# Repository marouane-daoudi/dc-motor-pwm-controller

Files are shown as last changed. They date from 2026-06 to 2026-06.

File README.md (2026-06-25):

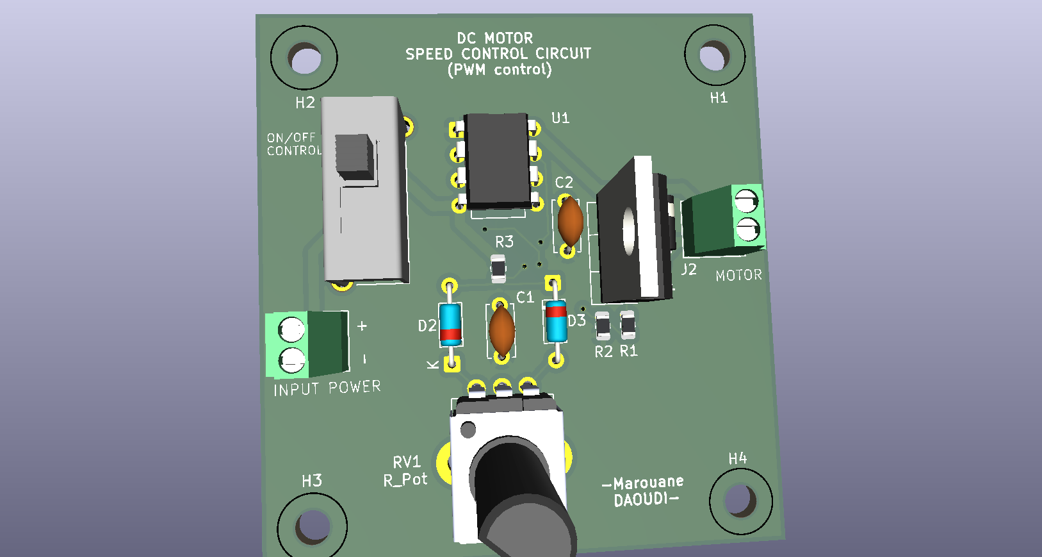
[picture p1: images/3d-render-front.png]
DC Motor PWM Speed Controller


# DC Motor PWM Speed Controller

A 2-layer PCB implementing a variable-speed DC motor controller 
using pulse-width modulation (PWM). The PWM signal is generated 
by a 555 timer in astable mode with an adjustable duty cycle 
controlled by a potentiometer. The design covers the full 
engineering workflow from circuit simulation in Proteus through 
PCB layout in KiCad to manufacturer-ready Gerber files.

---

## Specifications

| Parameter | Value |
|---|---|
| Supply voltage | 12V DC |
| Motor no-load current | 1.4A |
| MOSFET (Q1) | IRFZ44N — 49A continuous drain current |
| PWM frequency | ~1kHz–20kHz (adjustable via pot) |
| Duty cycle range | ~10% to ~90% |
| Timer IC | NE555 / LM555CN |
| Timing capacitor | 10nF ceramic |
| Speed control | 100kΩ potentiometer |
| PCB layers | 2-layer FR4 |
| Design tool | KiCad |
| Simulation tool | Proteus |

---

## Schematic

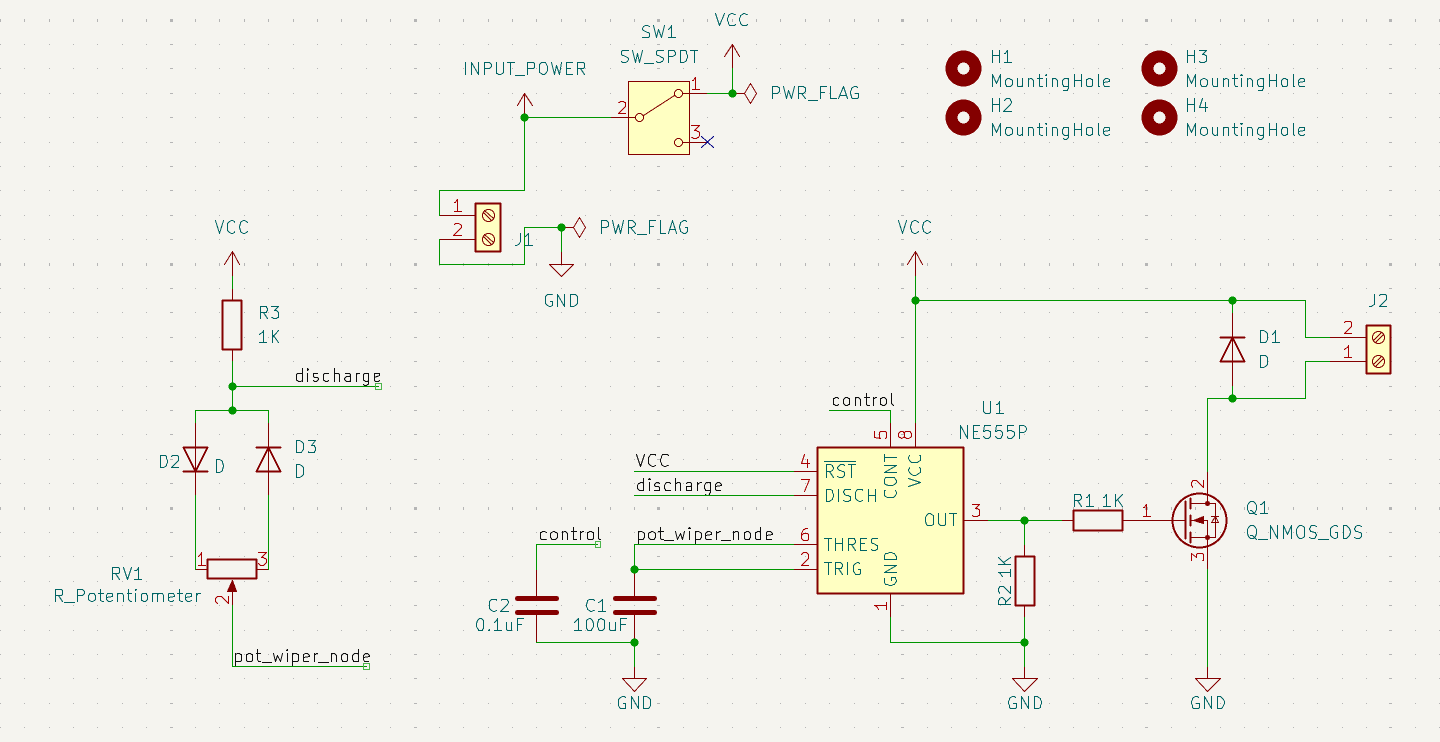
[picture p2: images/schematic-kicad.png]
KiCad Schematic


---

## How it works

### Why a MOSFET is needed

The LM555CN timer can source or sink a maximum of 200mA at its 
output pin. The DC motor used in this design draws 1.4A under 
no-load conditions — well beyond what the timer can drive 
directly. The IRFZ44N N-channel MOSFET (Q1) solves this by 
acting as a power switch controlled by the 555 output signal. 
With a rated continuous drain current of 49A and a low 
drain-to-source on-resistance, it handles the full motor current 
while being driven by the low-power 555 output.

### 555 timer PWM generation

The NE555 is configured in astable mode, continuously 
oscillating to produce a PWM square wave at pin 3 
(output_PWM_node). The key connections are:

- **Pin 8 (VCC)** → 12V power net
- **Pin 1 (GND)** → ground
- **Pin 4 (RESET)** → tied to VCC to keep the timer permanently 
  enabled (active LOW pin — must not be grounded)
- **Pin 5 (CV)** → bypassed to GND via 0.1µF ceramic capacitor 
  C2 to filter noise on the internal voltage divider and prevent 
  accidental frequency override
- **Pins 2 and 6** → connected together at the same node 
  (pot_wiper_node), feeding the same voltage to both internal 
  comparators of the 555 to sustain continuous oscillation

### Timing network and duty cycle control

The timing capacitor C1 (10nF ceramic) connects from 
pot_wiper_node to GND. Its charge and discharge paths are 
separated by two 1N4148 diodes (D2 and D3) and the 100kΩ 
potentiometer RV1, which is the key to independent duty cycle 
control:

- **Charge path (Ton):** current flows from VCC → R3 (1kΩ) → 
  D2 → left side of pot → wiper → C1 → GND
- **Discharge path (Toff):** C1 discharges through wiper → 
  right side of pot → D3 → pin 7 (discharge) → internal 
  transistor of 555 → GND

The 1N4148 diodes are rated for 300mA forward current, 
which is appropriate since the timing resistors are in the 
kΩ range and limit current well below this threshold.
The timing equations are:

$$
T_{on} = 0.693 \times (R_3 + R_{pot,left}) \times C_1
$$

$$
T_{off} = 0.693 \times R_{pot,right} \times C_1
$$

$$
T = T_{on} + T_{off}
$$

$$
f = \frac{1}{T}
$$

$$
D = \frac{T_{on}}{T_{on} + T_{off}}
$$

Rotating the potentiometer shifts resistance between the left 
and right sides, changing the Ton/Toff ratio and therefore the 
duty cycle — while the frequency stays approximately constant. 
The 10nF capacitor was chosen to produce a high PWM frequency 
(~1kHz and above), which ensures smooth motor rotation without 
audible buzzing or torque ripple.

Pin 7 (discharge) connects to the D3 node to complete the 
discharge route through the 555's internal transistor switch 
between pin 7 and pin 1.

### MOSFET gate drive

The PWM signal at output_PWM_node drives the gate of Q1 
(IRFZ44N) through two resistors:

- **R1 (1kΩ)** in series between pin 3 and the gate — limits 
  gate current and dampens switching ringing, also provides 
  protection if the MOSFET malfunctions
- **R2 (1kΩ)** from the gate node to GND — provides a 
  discharge path for the gate capacitance when the 555 output 
  goes LOW, ensuring the gate discharges cleanly to 0V and 
  preventing the MOSFET from remaining partially ON due to 
  residual gate charge

The MOSFET source connects directly to GND. Its drain connects 
to the negative terminal of the motor.

### Motor switching principle

When the 555 output is HIGH, the gate receives sufficient 
voltage to turn Q1 fully ON. The drain-to-source channel 
closes, completing the current path:

`12V → SW1 → Motor (+) → Motor (−) → MOSFET Drain → MOSFET Source → GND`

The motor runs. When the 555 output goes LOW, the gate 
discharges through R2, Q1 turns OFF, the current path breaks, 
and the motor coasts. This switching repeats at the PWM 
frequency. The motor's mechanical inertia averages the 
delivered power, producing a speed proportional to duty cycle:

$$
V_average = Duty cycle  ×  V_supply
$$

At 50% duty cycle the motor receives an effective average of 
6V. At 90% it receives approximately 10.8V — near full speed.

### Flyback protection

The DC motor is an inductive load. When Q1 switches OFF 
abruptly, the collapsing magnetic field in the motor coil 
generates a back-EMF voltage spike that can significantly 
exceed the supply voltage. D1 (1N4001) is placed across the 
motor terminals in reverse bias. This diode was chosen for its 
high peak current rating, providing a safe recirculating path 
for the back-EMF current and clamping the spike before it can 
damage Q1.

### ON/OFF control

SW1 (SPDT switch) is placed between the power supply input 
connector J1 and the power net. It provides a hard power 
cutoff independent of the potentiometer setting, allowing 
the motor to be stopped completely without adjusting speed 
control.

---

## Simulation

Circuit simulated and verified in Proteus before PCB layout.

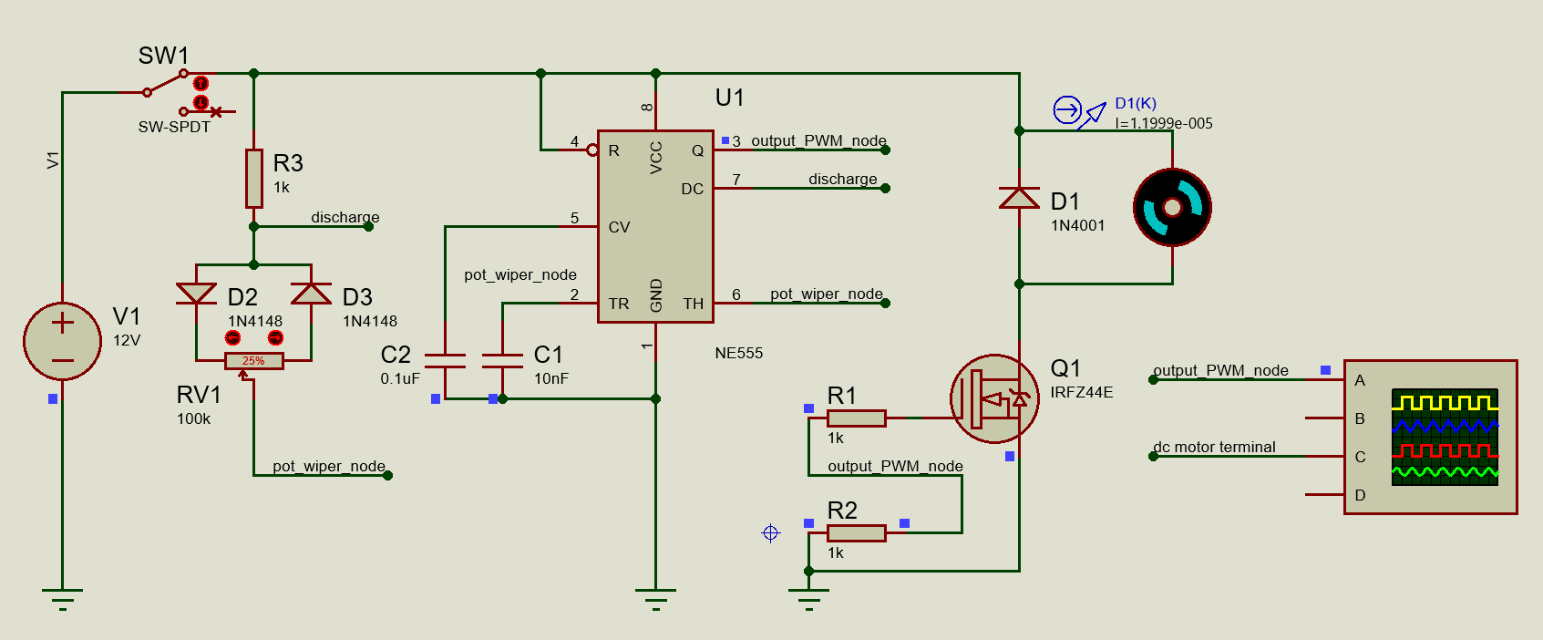
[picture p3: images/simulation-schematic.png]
Proteus Simulation


### Waveforms

**Low duty cycle — low motor speed:**
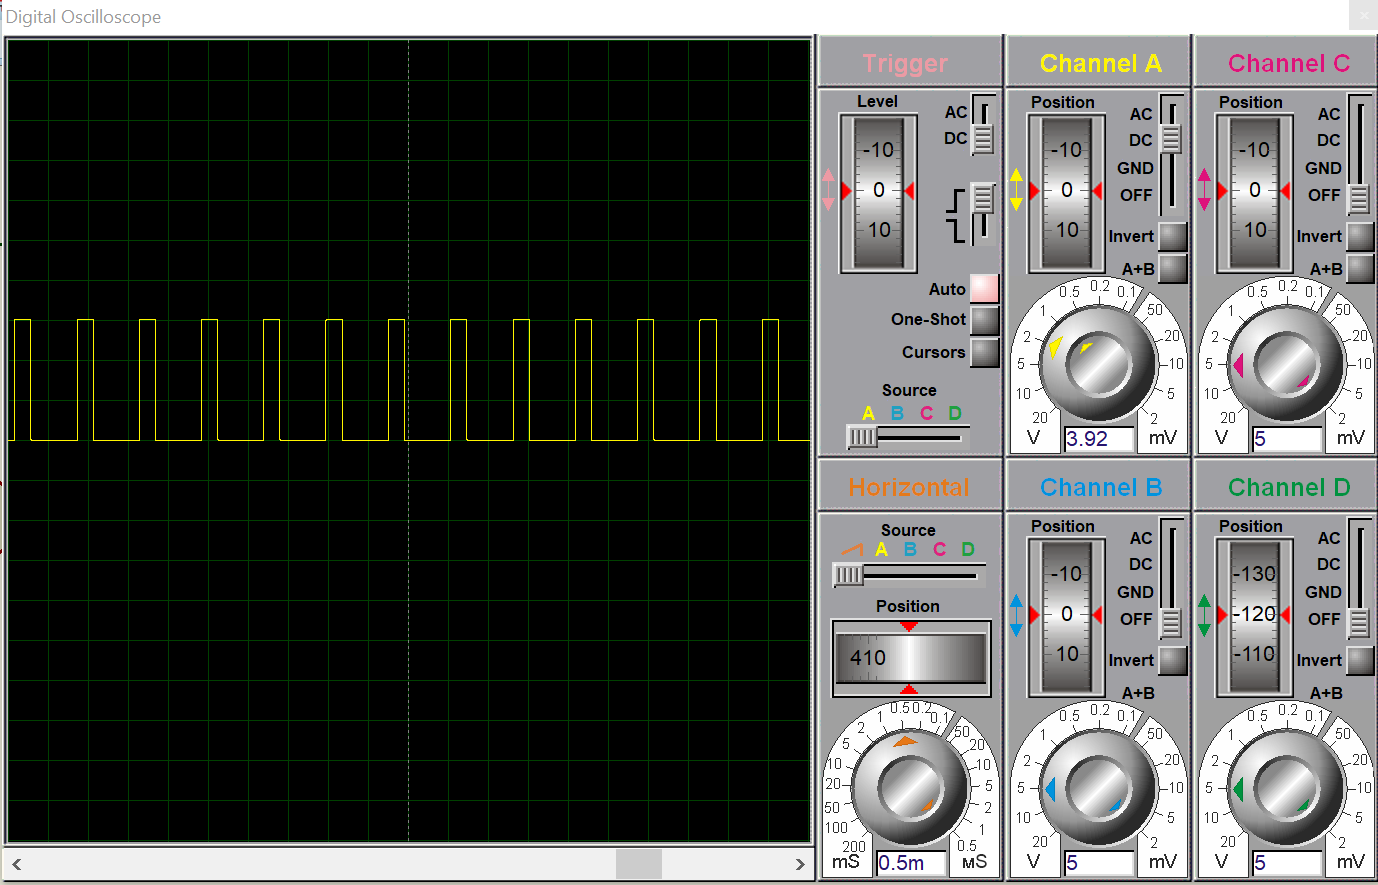
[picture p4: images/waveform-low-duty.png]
Low duty cycle


**Medium duty cycle — medium motor speed:**
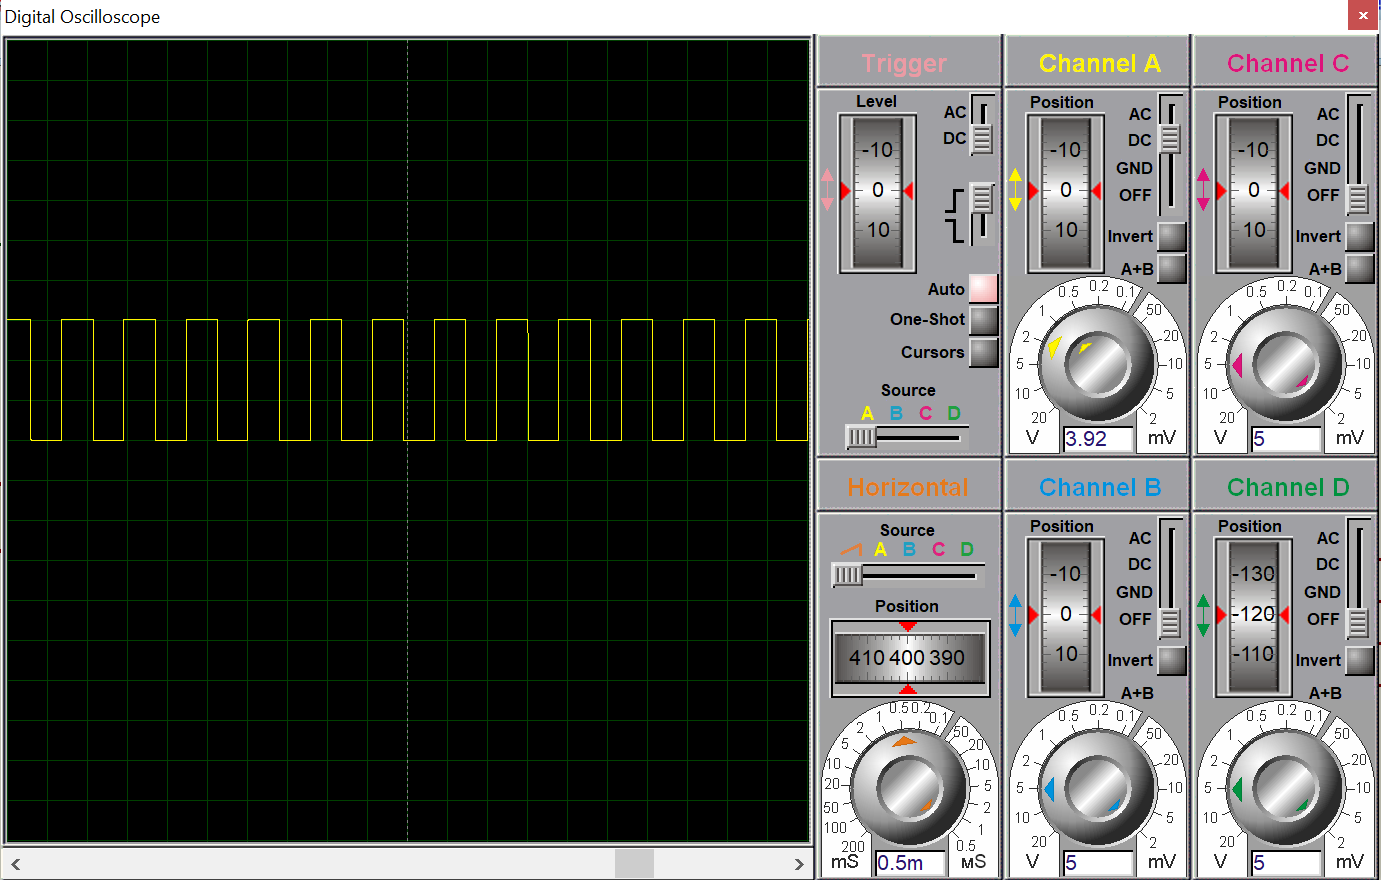
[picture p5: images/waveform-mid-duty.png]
Mid duty cycle


**High duty cycle — full motor speed:**
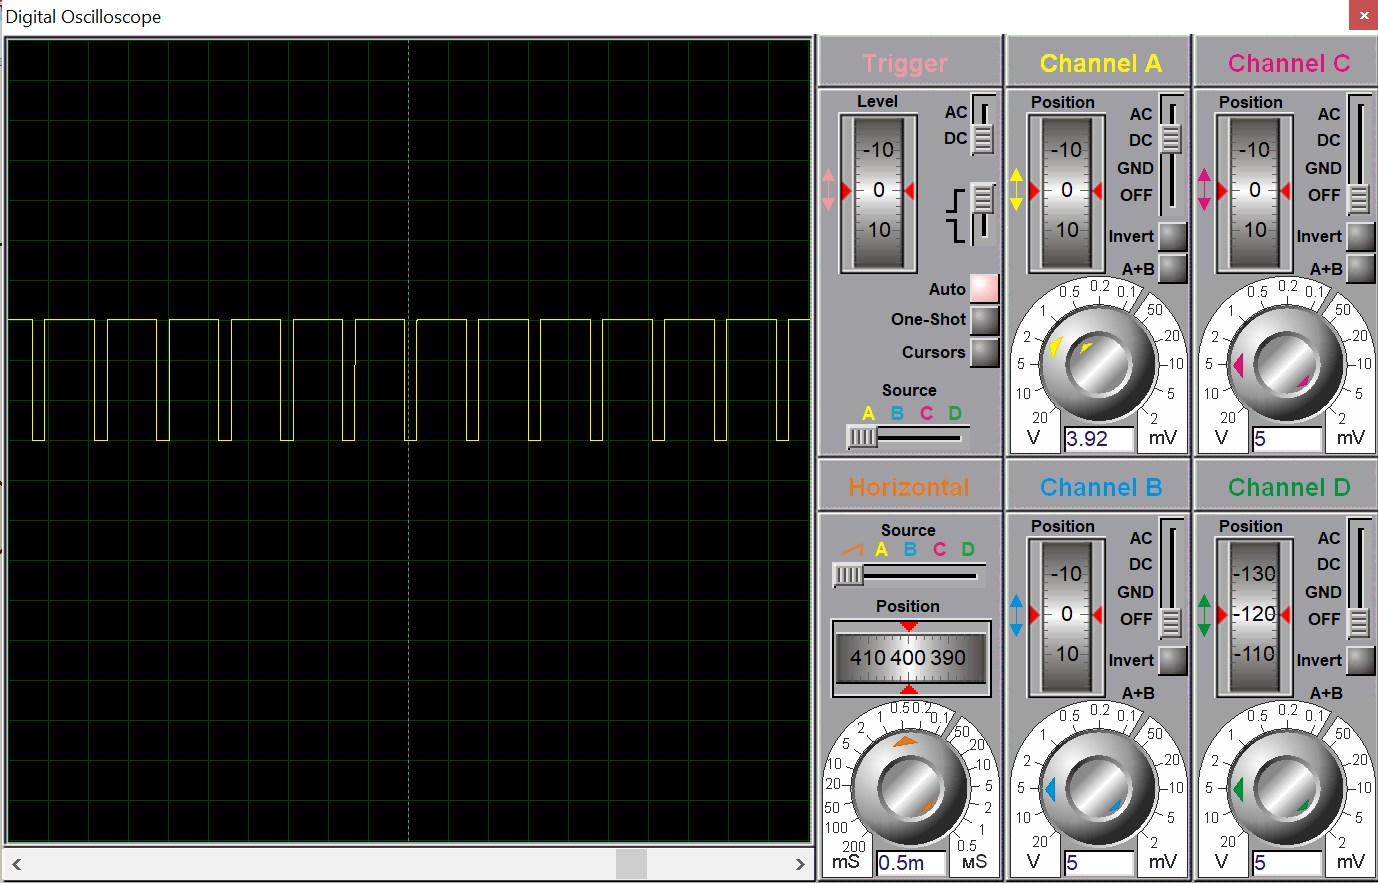
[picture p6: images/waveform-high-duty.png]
High duty cycle


### Simulation findings and fixes

During simulation two issues were identified and corrected:

**Issue 1 — Wrong timing capacitor value:** The initial 
capacitor value of 100µF produced a PWM frequency of 
approximately 5Hz, far too low for motor control and 
imperceptible on standard oscilloscope settings. Correcting 
to 10nF raised the frequency to the target range, producing 
smooth motor operation.

**Issue 2 — Insufficient gate drive:** With equal 1kΩ values 
for both R1 and R2, the voltage divider effect reduced gate 
voltage to approximately 5.25V — insufficient to fully enhance 
the IRFZ44N, which requires ~10V for minimum on-resistance. 
This prevented the motor from reaching full speed at 100% 
duty cycle. The fix was confirmed by ensuring the MOSFET 
source connects directly to GND with no intervening resistance 
in the return path.

---

## PCB Layout

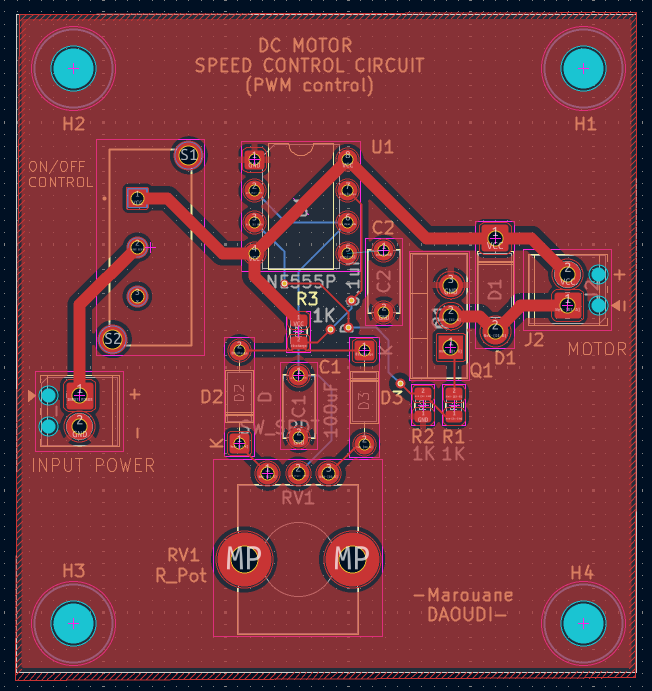
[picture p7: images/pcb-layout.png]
PCB Layout

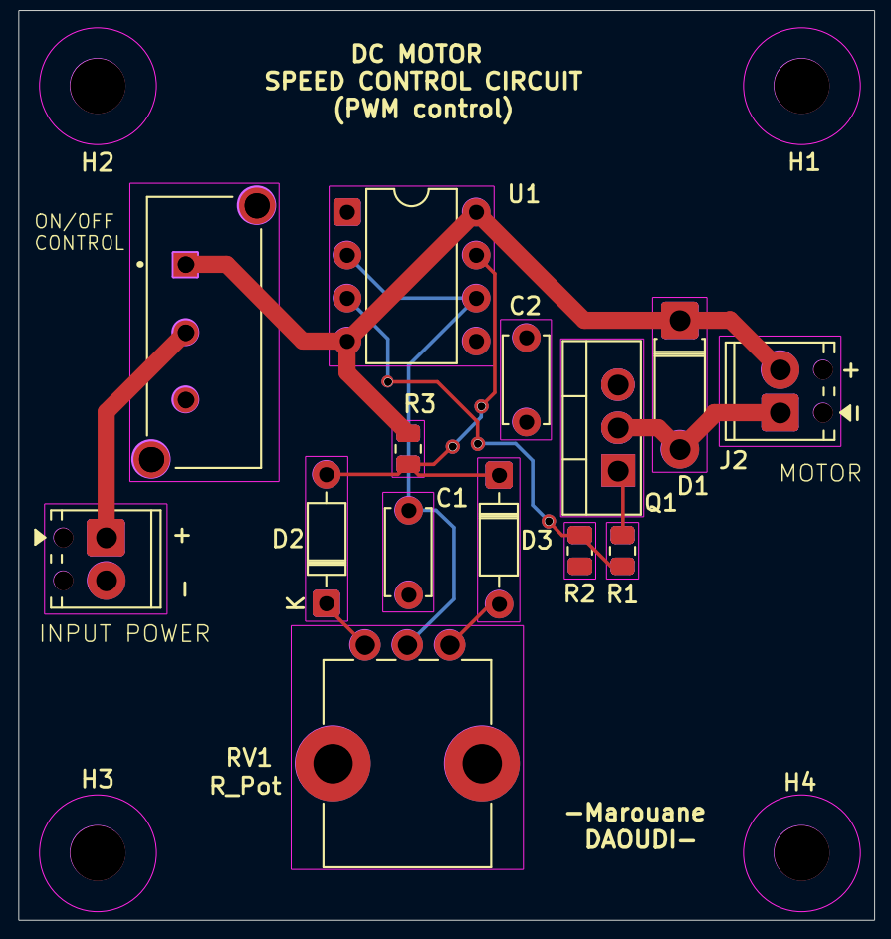
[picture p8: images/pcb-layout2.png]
PCB Layout


### Design decisions

- **Component placement** follows left-to-right signal flow — 
  power input (J1) on the left, 555 timing network in the 
  center, MOSFET and motor output (J2) on the right, 
  minimizing trace crossings and separating high-current motor 
  paths from the sensitive timing network
- **Power trace width** set to 1.5mm on motor current paths 
  to handle continuous current without resistive heating
- **Ground plane** on B.Cu layer provides a low-impedance 
  return path for all components and reduces EMI from the 
  switching MOSFET
- **Vias** used to connect front-layer components to the back 
  copper ground plane, resolving routing conflicts on a 
  2-layer board
- **D1 placement** as close as possible to J2 motor connector 
  to minimize the back-EMF inductive loop area
- **Screw terminals** for J1 and J2 for reliable external 
  wire connections without direct soldering to the board
- **Mixed assembly** — 0805 SMD for passive components 
  (compact placement), through-hole for 555 DIP-8, MOSFET 
  TO-220, potentiometer, and connectors (mechanical robustness)

---

## Manufacturing

Gerber files are in the `/gerbers` folder, verified using 
JLCPCB's online Gerber viewer. To order: zip the contents 
of the gerbers folder and upload to JLCPCB, PCBWay, or any 
standard FR4 PCB manufacturer. 2-layer board, no special 
requirements.

---

## Repository contents

| Folder | Contents |
|---|---|
| [`/kicad`](./Kicad) | KiCad schematic, PCB, and project files |
| [`/gerbers`](./gerbers) | Fabrication-ready Gerber and drill files |
| [`/simulation`](./Simulation) | Proteus simulation project file |
| [`/images`](./images) | 3D renders, PCB layout, waveform captures |

---

## Author

**Marouane Daoudi**  
Electrical Engineering student  
Designed in KiCad · Simulated in Proteus

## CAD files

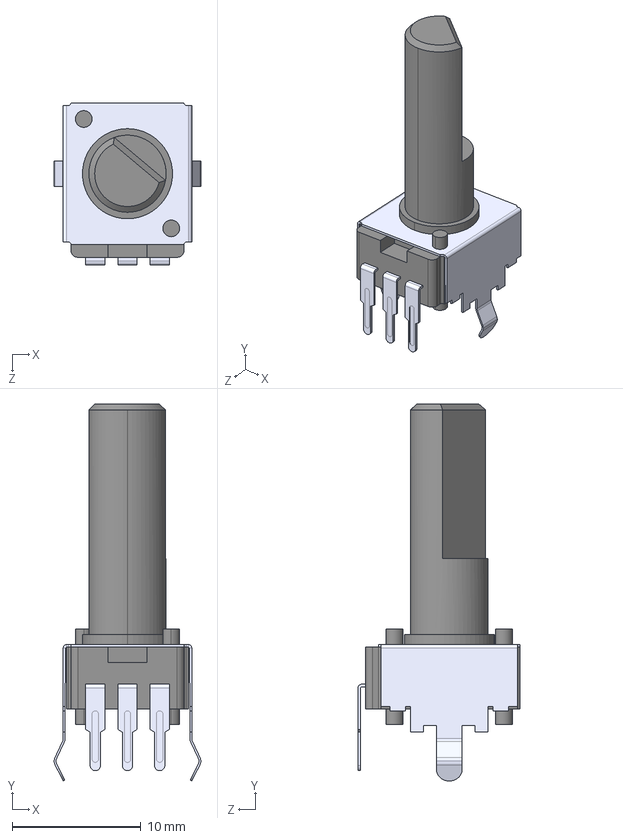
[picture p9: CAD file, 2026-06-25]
Kicad/3D_models/PTV09A-4225F-B104.STEP
11.4 x 29.3 x 12.6 mm

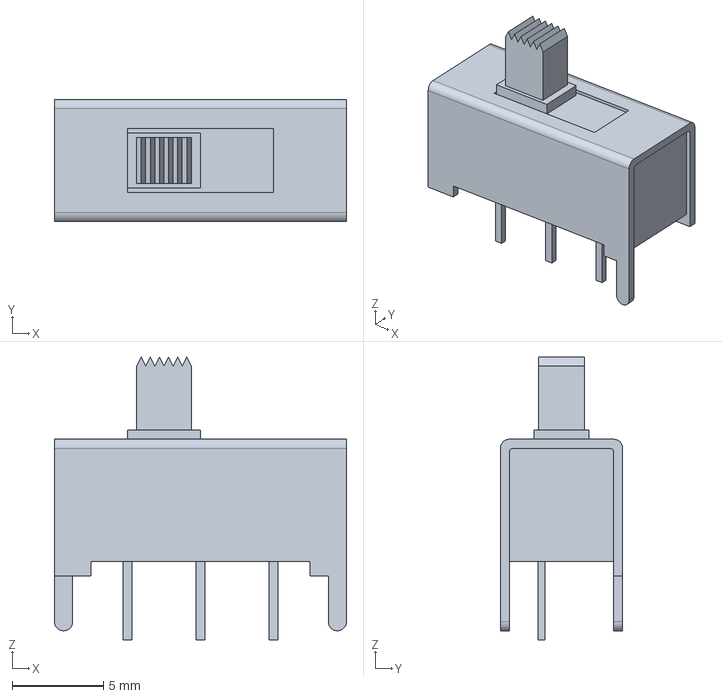
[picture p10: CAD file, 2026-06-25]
Kicad/3D_models/1825255-1.step
16.0 x 6.70 x 15.5 mm
